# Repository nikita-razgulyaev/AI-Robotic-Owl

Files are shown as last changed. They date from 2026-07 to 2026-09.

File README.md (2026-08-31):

<div align="center">

# 🦉 AI Robotic Owl

**Интерактивный робот-сова с искусственным интеллектом**
3D-печатная механика · 18 сервоприводов на ESP32-S3 · голосовой AI-сервер






</div>

---

## О проекте

**AI Robotic Owl** — роботизированная модель совы с ИИ: голосовой ассистент с характером, который слышит, видит, говорит и двигается. Проект объединяет три независимые, но тесно связанные части — 3D-печатный корпус, прошивку контроллера и AI-сервер.

## 📁 Структура репозитория

```
ai-robotic-owl/
├── AI-Robot-Server/          # Серверная часть: WebSocket-панель, LLM, STT, TTS
├── 3d-model-for-owl/         # 3D-модели корпуса для печати (Fusion 360 + STL)
├── arduino-owl-model/        # Прошивка ESP32-S3: сервоприводы, микрофон, камера, динамик
├── .gitattributes
└── README.md
```

---

## 🧠 Компоненты

### [`AI-Robot-Server/`](./AI-Robot-Server)

Голосовой AI-мозг робота: принимает аудио/видео с ESP32-S3 по WebSocket, распознаёт речь, генерирует ответы персонажа через LLM, синтезирует голос и рассчитывает позы сервоприводов — плюс веб-панель для мониторинга и ручного управления.

**Стек:** Python, FastAPI, WebSocket, Uvicorn · llama-cpp-python, ster-whisper, Silero, edge-tts · YOLOv8, MediaPipe, OpenCV · Qdrant

Полное описание архитектуры, API и запуска — в [`AI-Robot-Server/README.md`](./AI-Robot-Server/README.md).

### [`3d-model-for-owl/`](./3d-model-for-owl)

Набор 3D-моделей корпуса для FDM-печати: голова, тело, крылья, хвост, ноги — каждая деталь в отдельном боксе для удобства печати и сборки.

```
├── fusion/               # Исходники Fusion 360 (.f3d)
│   ├── head.f3d
│   ├── body.f3d
│   ├── wing box.f3d
│   ├── wings.f3d
│   ├── tail box.f3d
│   ├── tail.f3d
│   ├── leg box.f3d
│   └── legs.f3d
└── stl/                  # Готовые к печати STL по тем же узлам
    ├── head/...
    ├── body/...
    ├── wing box/...
    ├── wings/...
    ├── tail box/...
    ├── tail/...
    ├── leg box/...
    └── legs/...
```

**Материалs:** PLA/PETG

### [`arduino-owl-model/`](./arduino-owl-model)

Прошивка контроллера **ESP32-S3**: держит WebSocket-соединение с сервером, стримит аудио с микрофона и видео с камеры, воспроизводит голос через динамик, отрабатывает команды на 18 сервоприводов и управляет LED-подсветкой подставки.

**Особенности:**

- Управление **18 сервоприводами** с плавной интерполяцией движений
- Захват и стрим кадров с камеры (адаптивный FPS в зависимости от того, есть ли лицо в кадре)
- Захват и стрим аудио с микрофона, воспроизведение ответов на динамик
- Автопереподключение к Wi-Fi и WebSocket-серверу с heartbeat

---

## 🔧 Аппаратная платформа

| Компонент | Спецификация |
| --- | --- |
| Микроконтроллер | **ESP32-S3** (Wi-Fi, PSRAM) |
| Драйвер сервоприводов | PCA9685, 16-канальный, I2C (адрес `0x40`) |
| Сервоприводы | 18× SG90 / MG90S — 16 через PCA9685 + 2 напрямую с ESP32-S3 (крен головы, клюв) |
| Микрофон | INMP441, цифровой, шина I2S |
| Динамик | 4 Ом / 3 Вт + усилитель MAX98357A, I2S |
| Камера | OV2640 |
| Подсветка | Адресная LED-лента (подставка) |
| Питание сервоприводов | Внешний BEC 5V, 6A+ (отдельно от логики ESP32) |

> Полная распиновка I2C/I2S/камеры и таблица всех 18 индексов сервоприводов — в [`AI-Robot-Server/README.md`](./AI-Robot-Server/README.md#аппаратная-часть).

---

## 🚀 Быстрый старт

### 1. Аппаратная сборка

1. Распечатайте детали из [`3d-model-for-owl/stl`](./3d-model-for-owl/stl).
2. Установите сервоприводы в корпус согласно узлам сборки.
3. Подключите PCA9685 к ESP32-S3 по I2C и разместите микрофон, камеру и динамик по месту.
4. Обеспечьте отдельное питание 5V для сервоприводов с общей землёй с ESP32.

### 2. Прошивка контроллера

```bash
cd arduino-owl-model
# Откройте проект в Arduino IDE / PlatformIO
# Установите библиотеки: Adafruit PWM Servo Driver, ESP32Servo, ArduinoJson
# Выберите плату: ESP32S3 Dev Module
# Загрузите прошивку
```

### 3. Запуск AI-сервера

```bash
cd AI-Robot-Server
pip install -r requirements.txt
python websocket_server.py
```

Панель управления будет доступна по адресу `http://localhost:8765/panel`. Подробности — в README сервера.

---

## 🎯 Возможности

- 🎙️ Голосовой диалог с персонажем через AI (STT → LLM → TTS)
- 🦉 Живые движения: поворот и наклон головы, взмах крыльев, открытие клюва
- 👁️ Компьютерное зрение — слежение за лицом собеседника
- 🎭 Реакции на контекст разговора через позы сервоприводов
- 📱 Веб-панель для мониторинга, ручного управления и переключения режимов

---

## 📄 Лицензия

Проект распространяется под лицензией **[MIT](./LICENSE)**.

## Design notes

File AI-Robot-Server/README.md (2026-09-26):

<div align="center">

# 🦉 AI Robot Server — Сорен

**Локальный AI-сервер для роботизированной совы на ESP32-S3**
Голосовое управление · Компьютерное зрение · 18 сервоприводов

<p align="center">
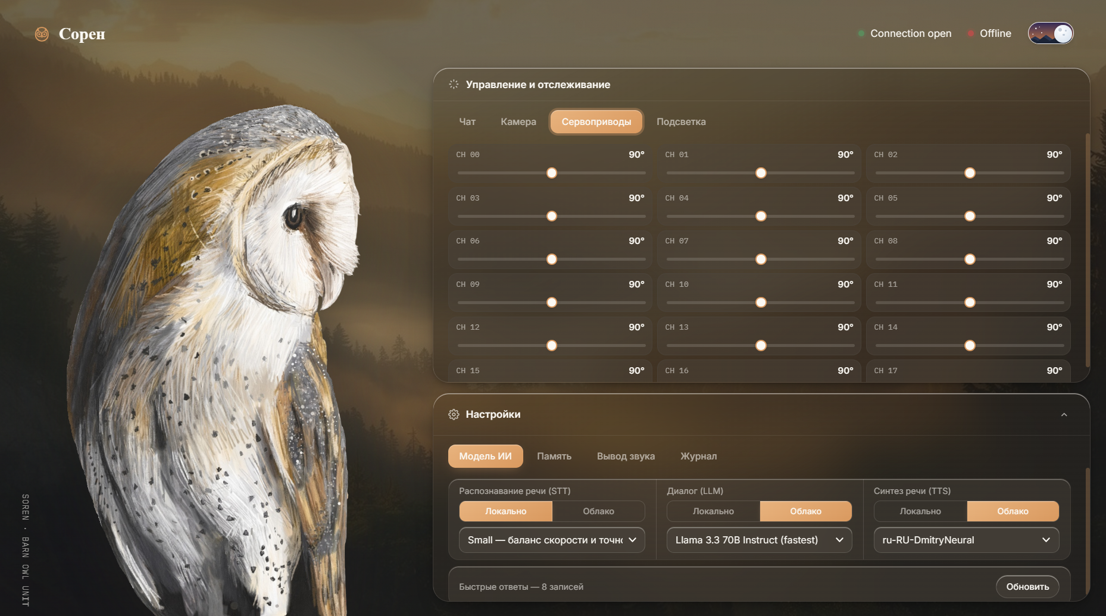
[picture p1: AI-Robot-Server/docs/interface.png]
Панель управления Robot AI Server
  
</p>






</div>

---

## О проекте

**Сорен** — амбарная сова, cтраж Великого Древа Га'Хула из книг Кэтрин Ласки «Легенды ночных стражей», воплощённая в виде физического робота на базе **ESP32-S3**. Этот репозиторий — серверная часть проекта: локальный AI-сервер, который распознаёт речь, генерирует ответы в характере персонажа, синтезирует голос и управляет 18 сервоприводами робота в реальном времени.

Проект объединяет полный voice AI pipeline (STT → LLM → TTS), компьютерное зрение и физическое поведение робота в единую систему с веб-панелью управления.

### Ключевые возможности

- 🎙️ **Голосовой диалог** — распознавание речи, генерация ответа персонажа, синтез голоса
- 🧠 **LLM-персонаж с памятью** — Qwen 7B (дообученный на датасете персонажа) + векторная память (Qdrant) + RAG по биографии и миру Сорена
- 👁️ **Компьютерное зрение** — детекция объектов (YOLOv8), трекинг позы и лиц (MediaPipe/OpenCV)
- 🎭 **Эмоциональный движок** — 7 эмоциональных состояний с уникальными позами сервоприводов и подсветкой глаз
- 🔀 **Local / Cloud переключение** — каждый AI-модуль (STT, LLM, TTS) можно переключать между локальным инференсом и облачным API одной кнопкой
- 🦾 **Управление 18 сервоприводами** — голова, крылья, тело, хвост, лапы, глаза
- 🌐 **Веб-панель управления** — голосовой и текстовый чат, ручное управление сервоприводами, переключение режимов, анимации

---

## Демонстрация переключения Local / Cloud

Каждый AI-модуль имеет независимую кнопку переключения режима — удобно для баланса между приватностью/офлайн-работой и качеством/скоростью.

| Модуль | Локально | Облачно |
| --- | --- | --- |
| **STT** 🎤 | faster-whisper (~500 МБ) | — |
| **LLM** 🧠 | Qwen 2.5 7B GGUF (~4.5 ГБ) | GitHub Models API (gpt-4o-mini) |
| **TTS** 🔊 | Silero (~120 МБ) | edge-tts (Microsoft, бесплатно) |

---

## Технологический стек

`FastAPI` · `faster-whisper` · `llama-cpp-python` · `PyTorch / Silero` · `edge-tts` · `YOLOv8` · `MediaPipe` · `OpenCV` · `webrtcvad` · `Qdrant`

| Компонент | Технология | Назначение |
| --- | --- | --- |
| WebSocket / HTTP сервер | FastAPI + Uvicorn + websockets | API для ESP32 и веб-панели |
| STT (речь → текст) | faster-whisper | Распознавание речи (локально) |
| LLM (языковая модель) | llama-cpp-python / GitHub Models API | Генерация ответов Сорена |
| TTS (текст → речь) | Silero (PyTorch) / edge-tts | Синтез голоса |
| Долгосрочная память | Qdrant (векторная БД) | Память диалогов и контекста |
| Vision | Ultralytics YOLOv8 + MediaPipe + OpenCV | Детекция объектов, позы, лиц |
| Audio VAD | webrtcvad | Определение начала/конца речи |
| Fine-tuning | PEFT (LoRA/QLoRA) + Transformers + Accelerate | Дообучение LLM на персонаже |
| Аудиообработка | soundfile + librosa | Конвертация форматов, ресемплинг |
| Конфигурация | python-dotenv | Переменные окружения |

---

## Архитектура

```
ESP32-S3 (робот) ──WebSocket──▶  FastAPI-сервер  ──▶  STT → LLM → TTS
     ▲   18 сервоприводов              │
     │   микрофон / динамик            ├──▶ Vision (YOLOv8, MediaPipe)
     │   камера                        ├──▶ Эмоциональный движок → позы сервоприводов
     └──────────── аудио/команды ◀─────┴──▶ Веб-панель управления (/panel)
```

---

## Быстрый старт

### 1. Установка зависимостей

```bash
python -m venv venv
venv\Scripts\activate      # Windows
source venv/bin/activate   # Linux / macOS

pip install -r requirements.txt
```

### 2. Настройка конфигурации

```bash
cp .env.example .env
# укажи GITHUB_MODELS_KEY в .env, если нужен облачный LLM
```

### 3. Загрузка моделей

```bash
python download_qwen.py   # LLM — Qwen 7B GGUF
python download_yolo.py   # Vision — YOLOv8
# Whisper и Silero скачаются автоматически при первом запуске
```

### 4. Запуск сервера

```bash
python websocket_server.py
```

Панель управления будет доступна по адресу: **http://localhost:8765/panel**

---

## Веб-панель управления

Панель (`/panel`) объединяет всё управление роботом в одном интерфейсе:

- Переключение режимов **Local / Cloud** для STT, LLM и TTS
- Переключение аудио-ввода (микрофон) и аудио-вывода (динамик)
- Голосовой чат и текстовый чат с Сореном
- Запуск анимаций: `wave`, `nod`, `shake_head`, `idle`
- Ручное управление каждым из 18 сервоприводов
- Отображение текущего статуса сервера и AI-модулей

---

## Персонаж Сорен

### Память и знания (RAG)

База знаний персонажа включает биографию, отношения с ключевыми персонажами, лор мира Га'Хула и философию — используется для контекстно-точных ответов в характере персонажа. Долгосрочная память диалогов хранится в векторной БД Qdrant.

---

## Аппаратная часть

Прошивка ESP32-S3 (`esp32_ai_robot_server.ino`) подключается к серверу по WebSocket (`/ws`, порт 8765), стримит аудио с микрофона и видео с камеры, принимает аудио-ответы и команды на сервоприводы, автоматически переподключается и восстанавливает прерванную фразу после обрыва Wi-Fi.

**Электроника:** ESP32-S3 (PSRAM) · PCA9685 (16-канальный I2C PWM-драйвер) · 18 сервоприводов · INMP441 (I2S-микрофон) · OV2640 (камера) · динамик с усилителем MAX98357A (I2S) · адресная LED-лента (подставка) · W5500 (Ethernet по SPI, резерв — Wi-Fi)

### Сервоприводы (18 каналов, индексы 0–17)

16 каналов идут через **PCA9685** (I2C, адрес `0x40`, 50 Гц, шина на GPIO 4/5), ещё 2 — напрямую с ESP32-S3 через LEDC PWM (50 Гц, 16 бит):

| Индекс | Имя | Назначение | Канал |
| --- | --- | --- | --- |
| 0 | `L_FLAP` | Левое крыло — взмах | PCA9685 |
| 1 | `L_FOLD` | Левое крыло — складывание  | PCA9685 |
| 2 | `R_FLAP` | Правое крыло — взмах | PCA9685 |
| 3 | `R_FOLD` | Правое крыло — складывание | PCA9685 |
| 4 | `WING_TILT` | Наклон крыльев (общий) | PCA9685 |
| 5 | `L_LEG_TURN` | Левая нога — поворот | PCA9685 |
| 6 | `L_LEG_FOLD` | Левая нога — сгиб | PCA9685 |
| 7 | `L_LEG_LIFT` | Левая нога — подъём | PCA9685 |
| 8 | `R_LEG_TURN` | Правая нога — поворот | PCA9685 |
| 9 | `R_LEG_FOLD` | Правая нога — сгиб | PCA9685 |
| 10 | `R_LEG_LIFT` | Правая нога — подъём | PCA9685 |
| 11 | `TAIL_YAW` | Хвост — поворот | PCA9685 |
| 12 | `TAIL_SPREAD` | Хвост — раскрытие | PCA9685 |
| 13 | `TAIL_LIFT` | Хвост — подъём | PCA9685 |
| 14 | `HEAD_YAW` | Голова — влево/вправо | PCA9685 |
| 15 | `HEAD_PITCH` | Голова — вперёд/назад | PCA9685 |
| 16 | `HEAD_ROLL_INDEX` | Голова — крен вбок | GPIO 38 |
| 17 | `BEAK_INDEX` | Открытие клюва | GPIO 39 |

Углы сервоприводов сглаживаются интерполяцией (шаг ≤4°, каждые 10 мс), чтобы движения выглядели плавно, а не рывками.

### Аудио (I2S)

| Узел | Роль | Пины (BCLK / WS·LRC / DATA) | Частота дискретизации |
| --- | --- | --- | --- |
| INMP441 | Микрофон (RX) | GPIO 1 / 3 / 2 | 16 кГц |
| MAX98357A | Усилитель/динамик (TX) | GPIO 40 / 41 / 42 | 48 кГц |

Динамик работает через кольцевой буфер в PSRAM с джиттер-буфером (~125 мс) и fade-in каждой новой фразы; во время воспроизведения и 400 мс после микрофон программно глушится, чтобы не ловить эхо.

### Камера (OV2640)

Данные: D0–D7 → GPIO 11, 9, 8, 10, 12, 18, 17, 16 · PCLK → GPIO 13 · VSYNC → GPIO 6 · HREF → GPIO 7 · SIOD/SIOC (I2C) → GPIO 14/21 · RESET → GPIO 15. Разрешение QVGA (320×240), адаптивный FPS: 3 кадра/с в режиме ожидания, 15 кадров/с при обнаруженном лице/активном диалоге.

### Подсветка подставки

Адресная LED-лента (NeoPixel, 60 светодиодов) на GPIO 47 — тёплая белая подсветка с плавной анимацией включения/выключения, управляется командой `backlight` с сервера.

### Сеть и связь

ESP32-S3 в первую очередь пытается поднять **Ethernet** (модуль W5500 по SPI); если за 4 секунды линк/IP не появились — автоматически откатывается на **Wi-Fi**. Выбор делается один раз при старте. В обоих случаях держится постоянное WebSocket-соединение с сервером (heartbeat каждые 30 с, таймаут 60 с, автопереподключение раз в 5 с). При обрыве связи во время озвучки фраза запрашивается заново после восстановления соединения.

**Ethernet (W5500, SPI):**

| Сигнал | GPIO | Примечание |
| --- | ---- | --- |
| SCK | 0 | strapping-пин (кнопка BOOT); не жать BOOT во время работы |
| MISO | 46 | input-only на ESP32-S3 |
| MOSI | 19 | физически совпадает с нативным USB (USB_D-) |
| CS | 20 | физически совпадает с нативным USB (USB_D+) |
| RST | 48 | |

Пины 19/20/43/44 (нативный USB и штатный UART0/CP2102) — единственный «дефолтный» вариант под SPI на этой плате (ESP32-S3-DevKitC-1, модуль WROOM-1 `-N16R8`, Octal PSRAM): GPIO22-25 не выведены на разъём, GPIO35-37 заняты Octal PSRAM. Текущая раскладка (SCK=0, MISO=46) освобождает GPIO43/44 обратно под UART0, чтобы Serial-логи оставались доступны через штатный CP2102-порт, пока Ethernet активен.

IP настраивается статически через `ETH.config(...)` **после** `ETH.begin()` (для DHCP-присвоения нужен DHCP-сервер в сети, которого нет при прямом соединении ПК↔робот через USB-Ethernet переходник). Адрес сервера, к которому подключается плата, задаётся константой `SERVER_HOST` в прошивке и должен совпадать со статическим IP компьютера на соответствующем сетевом адаптере.

---

## API

| Endpoint | Метод | Описание |
| --- | ----- | --- |
| `/` | GET | Статус сервера |
| `/status` | GET | Полный статус и режимы AI-модулей |
| `/audio_mode` | POST  | Переключение аудио (вход/выход) |
| `/ai_mode` | POST  | Переключение AI-модуля (stt/tts/llm) |
| `/speak` | POST  | Текст → LLM → TTS → аудио |
| `/voice` | POST  | Аудио → STT → LLM → TTS → аудио |
| `/panel` | GET | Веб-панель управления (HTML) |
| `/ws` | WS | WebSocket-канал для ESP32 |

---

## Тестирование

```bash
python check_model.py    # Проверка целостности LLM-модели
python test_server.py    # Тест сервера без физического ESP32
python test_github.py    # Тест GitHub Models API
python test_all.py       # Полное тестирование всех модулей
```

---

## Требования

- **Python:** 3.10 – 3.11
- **ОЗУ:** от 8 ГБ (для локального Qwen 7B)
- **Диск:** ~5 ГБ под модели
- **ОС:** Windows 10/11, Linux, macOS

---

## Структура проекта

```
robot_server/
├── websocket_server.py      # Главный WebSocket-сервер + веб-панель
├── config.yaml               # Основной конфиг (модели, сеть, режимы)
├── requirements.txt
├── .env / .env.example
├── config/                  # Настройки сервера, AI, сервоприводов, анимаций
├── modules/                 # AI-модули: stt, tts, llm, vision, robot_brain,
│                             #   servo_controller, audio_buffer, fuzzy_matcher, memory
├── character/                # System prompt, RAG-чанки, карта эмоций Сорена
├── audio_cache/              # Заранее сгенерированные аудио-ответы (quick answers)
├── memory/                   # Долгосрочная память диалогов
├── qdrant_storage/            # Локальное хранилище векторной БД Qdrant
├── models/                   # AI-модели (скачиваются автоматически)
├── llama-bin/                 # Бинарники llama.cpp для локального LLM-инференса
├── datasets/                  # Датасеты для fine-tuning персонажа
├── scripts/                  # Загрузка/подготовка моделей, датасета, fine-tuning
├── static/panel/              # Ассеты веб-панели
├── docs/                      # Документация, скриншоты
├── .github/                   # CI/шаблоны GitHub
└── .vscode/                   # Настройки редактора
```

---

## Лицензия

Проект распространяется под лицензией **[MIT](./LICENSE)**.

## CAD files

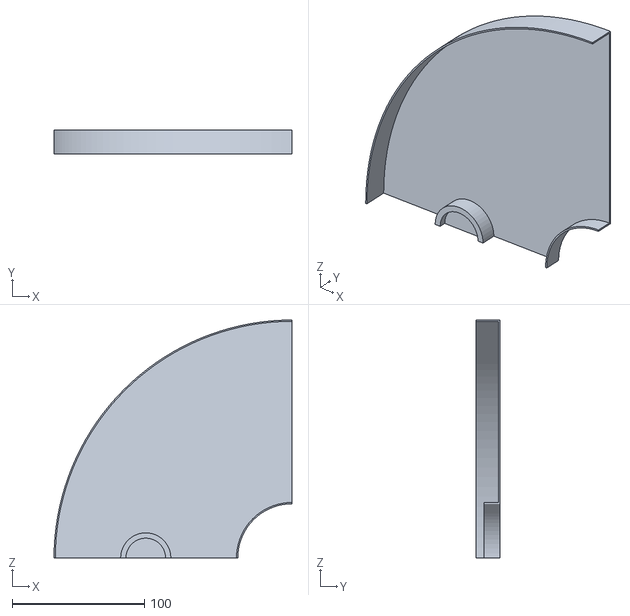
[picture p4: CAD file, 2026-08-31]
3d-model-for-owl/stl/base/base (2).stl
180.0 x 18.0 x 180.0

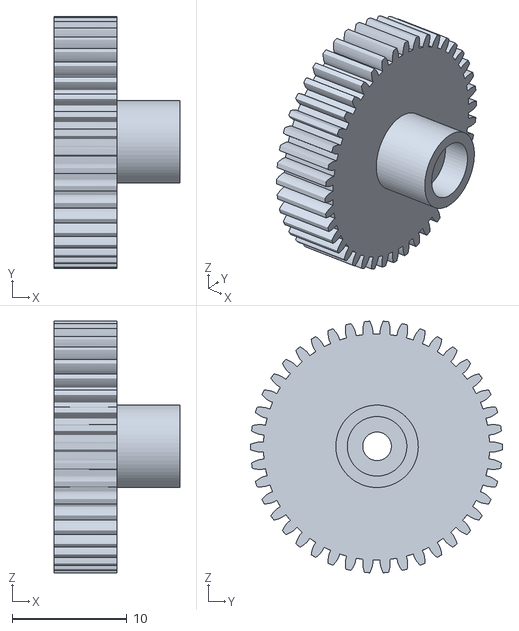
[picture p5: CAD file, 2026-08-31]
3d-model-for-owl/stl/body/tilt gear.stl
11.0 x 22.0 x 22.0

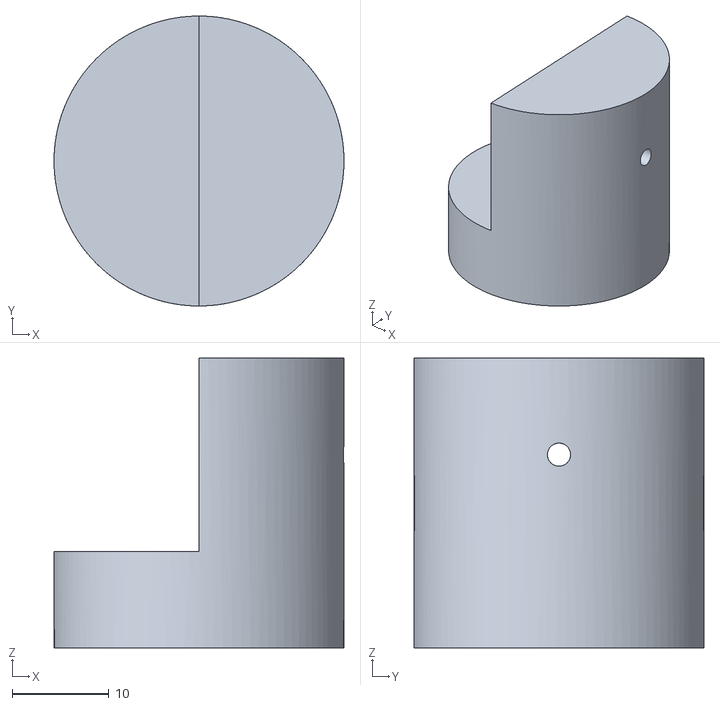
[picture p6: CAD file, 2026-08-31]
3d-model-for-owl/stl/clamp/clamp.stl
30.0 x 30.0 x 30.0

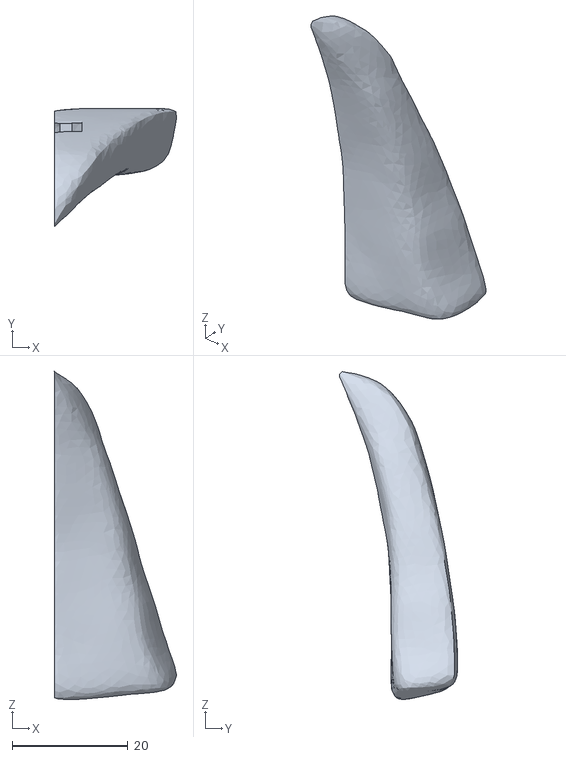
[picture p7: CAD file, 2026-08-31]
3d-model-for-owl/stl/head/left lower jaw.stl
21.1 x 20.5 x 56.7

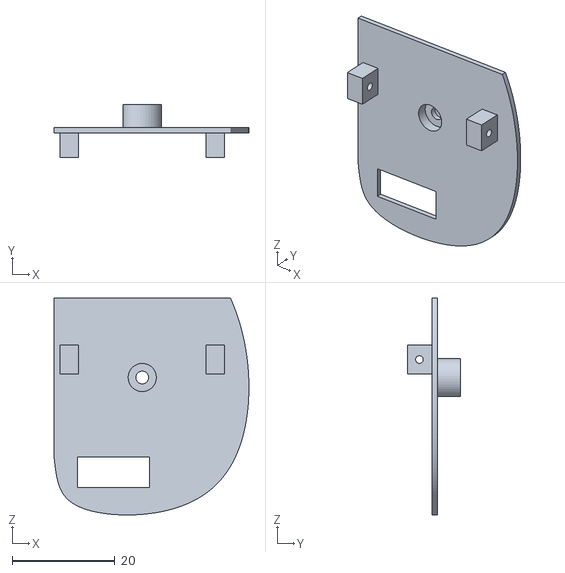
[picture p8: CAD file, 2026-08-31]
3d-model-for-owl/stl/leg box/left leg box head.stl
38.0 x 10.3 x 42.3

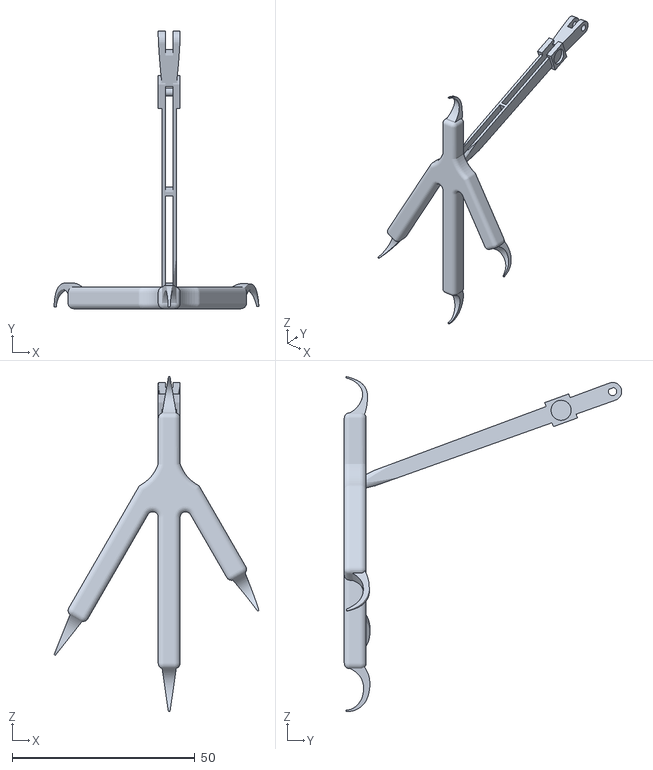
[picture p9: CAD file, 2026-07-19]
3d-model-for-owl/stl/legs/part 3.stl
56.0 x 75.9 x 91.6

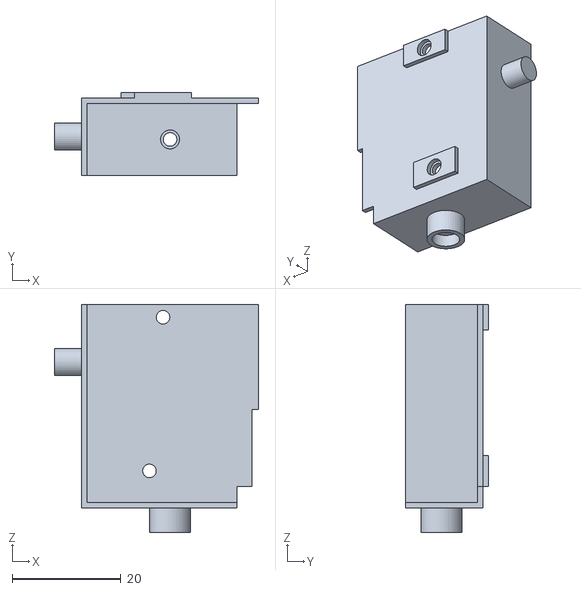
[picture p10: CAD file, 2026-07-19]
3d-model-for-owl/stl/tail box/tail box head.stl
37.6 x 15.3 x 42.0

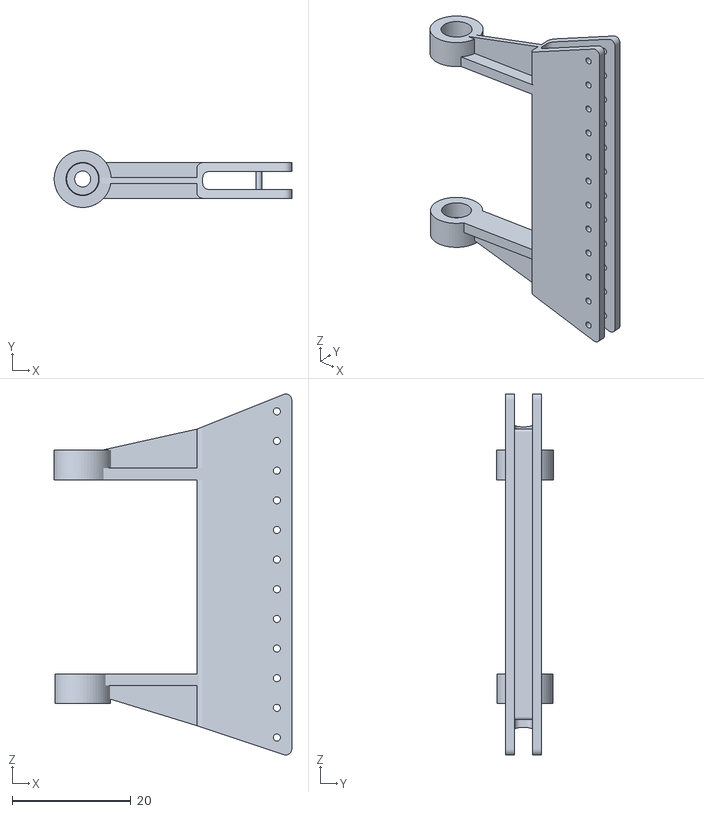
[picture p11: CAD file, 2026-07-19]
3d-model-for-owl/stl/tail/tail.stl
40.1 x 9.59 x 60.9

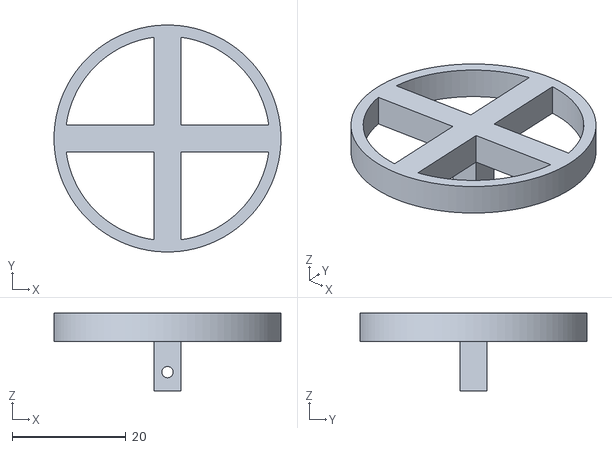
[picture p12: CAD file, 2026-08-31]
3d-model-for-owl/stl/wing box/roll 1.stl
40.0 x 40.0 x 13.7

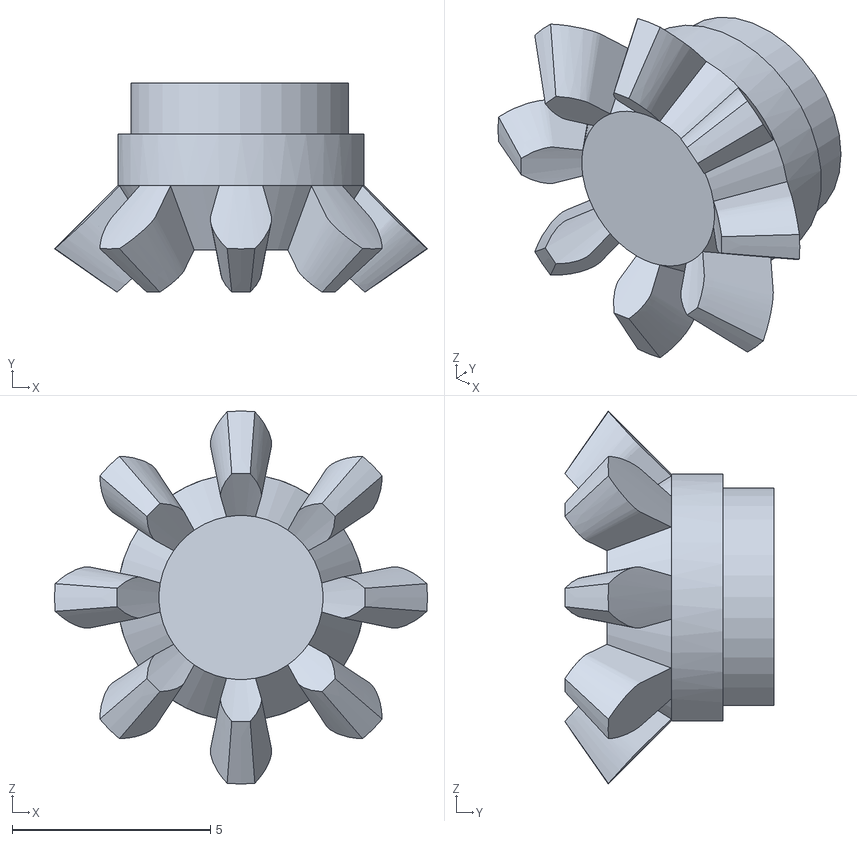
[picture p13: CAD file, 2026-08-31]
3d-model-for-owl/stl/wings/left pt 1 bl gr.stl
9.41 x 5.28 x 9.41

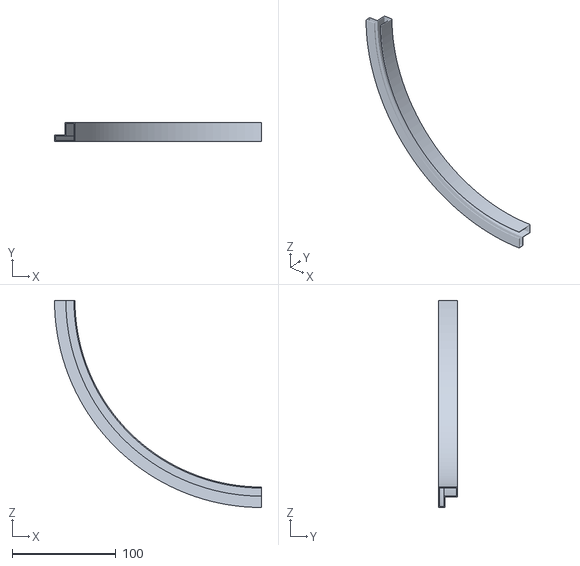
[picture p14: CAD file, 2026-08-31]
3d-model-for-owl/stl/base/light ring (1).stl
200.0 x 18.0 x 200.0

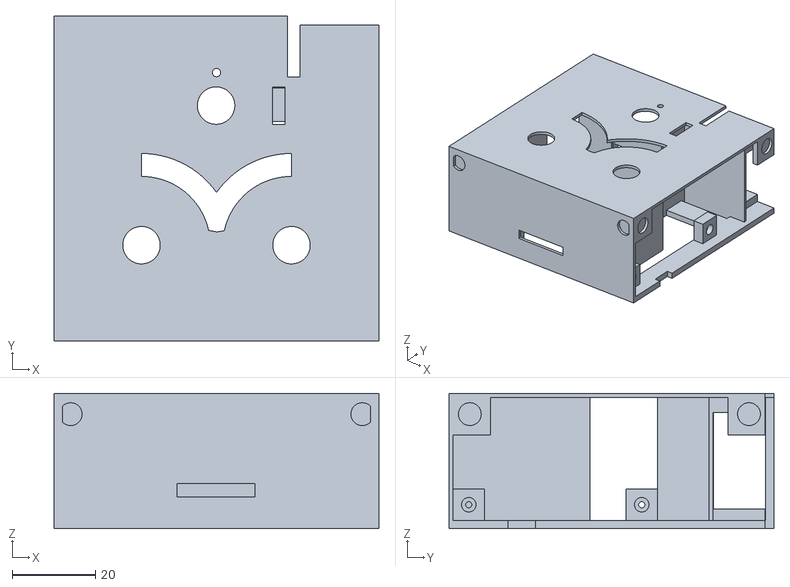
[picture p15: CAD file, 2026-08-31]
3d-model-for-owl/stl/body/body(2).stl
78.0 x 78.0 x 32.5

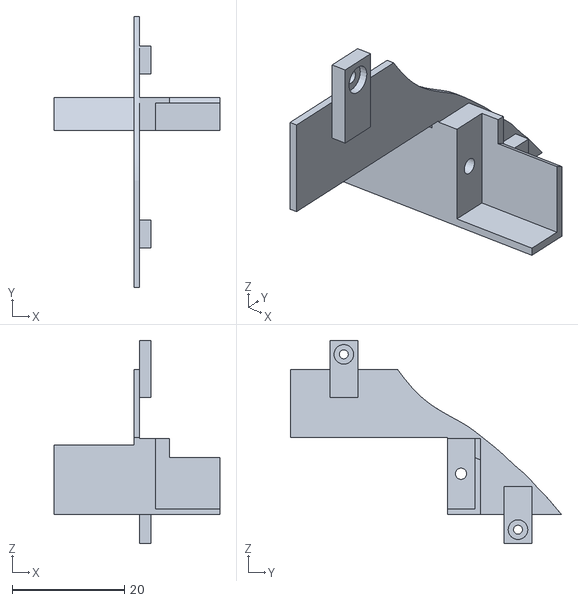
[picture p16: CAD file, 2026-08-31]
3d-model-for-owl/stl/head/forehead.stl
29.5 x 48.2 x 36.2

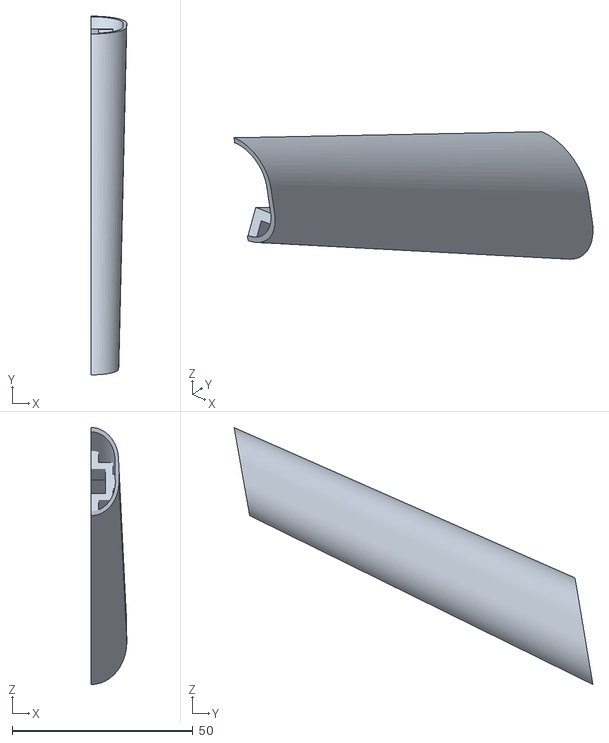
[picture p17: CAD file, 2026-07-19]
3d-model-for-owl/stl/legs/part 2 case (2).stl
9.86 x 99.3 x 71.1

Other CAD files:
3d-model-for-owl/stl/leg box/right leg box head.stl
3d-model-for-owl/stl/tail box/tail box.stl
3d-model-for-owl/stl/tail/holder 1.stl
3d-model-for-owl/stl/wing box/fold gear.stl
3d-model-for-owl/fusion/base.f3d
3d-model-for-owl/fusion/body.f3d
3d-model-for-owl/fusion/clamp.f3d
3d-model-for-owl/fusion/eyes.f3d
3d-model-for-owl/fusion/leg box.f3d
3d-model-for-owl/fusion/tail box.f3d
3d-model-for-owl/fusion/tail.f3d
3d-model-for-owl/fusion/wing box.f3d
3d-model-for-owl/fusion/wings.f3d
3d-model-for-owl/stl/base/base (1).stl
3d-model-for-owl/stl/base/base (3).stl
3d-model-for-owl/stl/base/base (4).stl
3d-model-for-owl/stl/base/light ring (2).stl
3d-model-for-owl/stl/base/light ring (3).stl
3d-model-for-owl/stl/base/light ring (4).stl
3d-model-for-owl/stl/base/outer ring (1).stl
3d-model-for-owl/stl/base/outer ring (2).stl
3d-model-for-owl/stl/base/outer ring (3).stl
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

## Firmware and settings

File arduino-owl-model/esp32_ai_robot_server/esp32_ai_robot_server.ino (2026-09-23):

/* 🦉 Robot ESP32-S3 Firmware - Soren */

#include <WiFi.h>
#include <ETH.h>
#include <SPI.h>
#include <WebSocketsClient.h>
#include <Wire.h>
#include <Adafruit_PWMServoDriver.h>
#include <driver/i2s.h>
#include <esp_camera.h>
#include <ArduinoJson.h>
#include <Adafruit_NeoPixel.h>
#include <esp_task_wdt.h>

// ==================== КОНФИГУРАЦИЯ ====================
const char* WIFI_SSID = "TP-Link_208E";
const char* WIFI_PASSWORD = "31267649";
const char* SERVER_HOST = "192.168.50.10";  // статический IP ПК на адаптере TP-LINK USB-Ethernet
const char* DEVICE_KEY = "";
const int SERVER_PORT = 8765;

// ---------- ETHERNET (модуль W5500 по SPI) ----------
// GPIO0/45/46 — strapping-пины ESP32-S3: их уровень чип читает В МОМЕНТ
// СБРОСА, чтобы выбрать режим загрузки. Внешнее устройство на них (было тут
// раньше — 0=MOSI, 46=CS) срывает это определение при каждом
// авто-сбросе/заливке ("Wrong boot mode detected"). Поэтому SPI переехал на
// GPIO19/20/43/44 — ни один из них не strapping и не PSRAM (33-37).
//
// ВАЖНО: GPIO43/44 по умолчанию — консольный UART на CP2102 ("UART"-порт).
// Заняв их под Ethernet, Serial-вывод для отладки нужно смотреть через
// ВТОРОЙ, нативный USB-порт платы ("USB"), и в Arduino IDE включить
// Tools → USB CDC On Boot → Enabled — иначе Serial.print() будет уходить в
// никуда.
// ПЛАТА: ESP32-S3-DevKitC-1, модуль WROOM-1 -N16R8 (Octal PSRAM).
// ЭКСПЕРИМЕНТ: пробуем вернуть SCK/MISO на strapping-пины 0/46, но НЕ в
// тех же ролях, что раньше сорвали загрузку (было 0=MOSI, 46=CS).
// Теория: SCK всегда ведёт ESP32 (мастер), W5500 (ведомый) его не тянет;
// MISO — вход для ESP32, GPIO46 к тому же input-only. Раньше проблема
// была именно с MOSI/CS на strapping-пинах — не факт, что SCK/MISO
// поведут себя так же. ПРОВЕРИТЬ: после заливки следить за выводом
// esptool — если снова "Wrong boot mode detected"/сбои автосброса на
// каждой заливке, откатывать на 43/44 (см. предыдущую версию комментария
// в истории правок).
#define ETH_PHY_TYPE   ETH_PHY_W5500
#define ETH_PHY_ADDR   1
#define ETH_PHY_CS     20
#define ETH_PHY_IRQ    -1
#define ETH_PHY_RST    48
#define ETH_SPI_SCK    0
#define ETH_SPI_MISO   46
#define ETH_SPI_MOSI   19

#define ETH_CONNECT_TIMEOUT_MS 4000  // сколько ждём линк+DHCP на Ethernet при старте,
                                      // прежде чем откатиться на Wi-Fi
#define WIFI_FALLBACK_TIMEOUT_MS 20000

bool ethConnected = false;      // Ethernet реально поднят и получил IP прямо сейчас
bool wifiFallbackActive = false; // на этом старте работаем через Wi-Fi (Ethernet не найден/не подключен)

// ---------- СЕРВОПРИВОДЫ ----------
Adafruit_PWMServoDriver pca = Adafruit_PWMServoDriver(0x40);
const int PCA_FREQ = 50;
const int SERVO_17_PIN = 38;
const int SERVO_18_PIN = 39;

// ESP32-S3 аппаратно поддерживает МАКСИМУМ 14 бит разрешения на канал LEDC
// (в отличие от классического ESP32, где было 20 бит). Раньше здесь стояло 16 —
// ledcAttach() с недопустимым разрешением тихо возвращает false и канал вообще
// не настраивается, поэтому ledcWrite() на GPIO 38/39 ничего не делал — именно
// поэтому сервы HEAD_ROLL/BEAK "не работали".
#define SERVO_GPIO_LEDC_RES_BITS 14
#define SERVO_GPIO_LEDC_MAX_DUTY ((1 << SERVO_GPIO_LEDC_RES_BITS) - 1)  // 16383

// -------------------- ИМЕНОВАННЫЕ ИНДЕКСЫ СЕРВО --------------------
#define L_FLAP          0   // Левое крыло — взмах
#define L_FOLD          1   // Левое крыло — складывание
#define R_FLAP          2   // Правое крыло — взмах
#define R_FOLD          3   // Правое крыло — складывание
#define WING_TILT       4   // Наклон крыльев (общий)
#define L_LEG_TURN      5   // Левая нога — поворот
#define L_LEG_FOLD      6   // Левая нога — сгиб
#define L_LEG_LIFT      7   // Левая нога — подъём
#define R_LEG_TURN      8   // Правая нога — поворот
#define R_LEG_FOLD      9   // Правая нога — сгиб
#define R_LEG_LIFT      10  // Правая нога — подъём
#define TAIL_YAW        11  // Хвост — поворот
#define TAIL_SPREAD     12  // Хвост — раскрытие
#define TAIL_LIFT       13  // Хвост — подъём
#define HEAD_YAW        14  // Голова — влево/вправо (канал PCA9685)
#define HEAD_PITCH      15  // Голова — вперёд/назад (канал PCA9685)
#define HEAD_ROLL_INDEX 16  // Голова — крен вбок. Физически SERVO_17_PIN = GPIO 38
#define BEAK_INDEX      17  // Открытие клюва.       Физически SERVO_18_PIN = GPIO 39

#define PCA_SERVO_COUNT 16  // сколько первых индексов (0-15) идут через PCA9685

#define SERVO_MAX_STEP 3        // потолок скорости (град/тик = 10мс) — верхний предел даже для больших скачков цели
#define SERVO_EASE_FACTOR 0.12  // доля оставшегося расстояния до цели, проходимая за один тик (плавное подтормаживание к концу)
#define SERVO_UPDATE_MS 10
#define SERVO_DEAD_ZONE 1

// ---------- ПОДСВЕТКА ----------
#define STAND_LED_PIN   47
#define STAND_LED_COUNT 60
Adafruit_NeoPixel standLed(STAND_LED_COUNT, STAND_LED_PIN, NEO_GRB + NEO_KHZ800);

#define WARM_WHITE_R 255
#define WARM_WHITE_G 200
#define WARM_WHITE_B 140
bool standBacklightOn = false;

// ---------- I2S ПИНЫ ----------
#define I2S_MIC_BCLK    1
#define I2S_MIC_WS      3
#define I2S_MIC_DIN     2

#define I2S_AMP_BCLK    40
#define I2S_AMP_LRC     41
#define I2S_AMP_DOUT    42

#define SAMPLE_RATE 16000
#define SPEAKER_SAMPLE_RATE 48000

// ---------- КАМЕРА ----------
#define PWDN_GPIO_NUM    -1
#define RESET_GPIO_NUM   15
#define XCLK_GPIO_NUM    -1
#define SIOD_GPIO_NUM    14
#define SIOC_GPIO_NUM    21

// Возвращено на QVGA (320x240) — на HQVGA (240x176) детектор лица на
// зашумлённой ИК-картинке стабильно не проходил порог уверенности
// (FACE_DETECTOR_CONFIDENCE). Прирост FPS слежения берём не за счёт
// разрешения, а за счёт освобождённого CV-потока (убрано слежение за
// губами) и CAM_FPS_FACE ниже.
#define DETECT_FRAME_SIZE  FRAMESIZE_QVGA

#define CAM_FPS_IDLE  3
#define CAM_FPS_FACE  15
unsigned long videoFrameIntervalMs = 1000 / CAM_FPS_IDLE;
unsigned long lastVideoFrameMs = 0;
bool lastFaceDetected = false;

// ==================== ГЛОБАЛЬНЫЕ ====================
WebSocketsClient webSocket;
bool isConnected = false;

int currentServoAngles[18];
int targetServoAngles[18];
unsigned long lastServoUpdateMs = 0;

String currentEyeLed = "soft_white_low";
String audioMode = "robot";

// ---------- МИКРОФОН ----------
#define AUDIO_BUFFER_SIZE 1024
int16_t audioBuffer[AUDIO_BUFFER_SIZE];

#define AUDIO_CHUNK_SAMPLES 480
#define AUDIO_CHUNK_BYTES (AUDIO_CHUNK_SAMPLES * 2)

uint8_t micAccum[AUDIO_CHUNK_BYTES * 8];
size_t micAccumLen = 0;

#define MIC_NOISE_GATE 150
#define MIC_SILENCE_TIMEOUT 1000
unsigned long silenceStartMs = 0;
bool micStreamConfirmed = false;

// ---------- ДИНАМИК (ring buffer) ----------
#define SPK_BUFFER_SIZE 131072
uint8_t* spkRingBuffer = nullptr;
volatile size_t spkWriteIdx = 0;
volatile size_t spkReadIdx = 0;
volatile size_t spkDataLen = 0;

#define SPK_PREBUFFER_BYTES     12000  // ~125 мс на 48кГц/16-бит — запас на джиттер сети
#define SPK_PREBUFFER_STALL_MS  350    // столько ждём тишину, прежде чем считать накопление законченным
#define SPK_END_SILENCE_MS      900    // тишина дольше этого = фраза реально закончилась
bool spkPrebuffering = true;
bool spkEnded = true;               // true = сейчас полная тишина, новых данных не ждём
volatile unsigned long lastSpkPushMs = 0;

// ---------- ВОССТАНОВЛЕНИЕ ПОСЛЕ ОБРЫВА WI-FI ----------
bool utteranceInterrupted = false;

// ---------- КАМЕРА ----------
static uint8_t videPacket[16384];

// ---------- HEARTBEAT ----------
#define HEARTBEAT_INTERVAL_MS 30000
#define HEARTBEAT_TIMEOUT_MS  60000
unsigned long lastHeartbeatSentMs = 0;
unsigned long lastHeartbeatRecvMs = 0;

// ---------- ЭХО-ПОДАВЛЕНИЕ ----------
// Время (мс), на которое микрофон "глухнет" после окончания аудио в буфере,
// чтобы не схватить реверберацию из динамика
#define MIC_DEAF_MS_AFTER_AUDIO 400
static unsigned long lastSpkActiveMs = 0;

// ==================== СЕТЬ (Ethernet первым, Wi-Fi — резерв) ====================
void onNetworkEvent(arduino_event_id_t event, arduino_event_info_t info) {
  switch (event) {
    case ARDUINO_EVENT_ETH_START:
      Serial.println("[ETH] Интерфейс стартовал");
      ETH.setHostname("soren-owl");
      break;
    case ARDUINO_EVENT_ETH_CONNECTED:
      Serial.println("[ETH] Кабель на линке");
      break;
    case ARDUINO_EVENT_ETH_GOT_IP:
      Serial.print("[ETH] ✅ IP получен: ");
      Serial.println(ETH.localIP());
      ethConnected = true;
      break;
    case ARDUINO_EVENT_ETH_LOST_IP:
    case ARDUINO_EVENT_ETH_DISCONNECTED:
    case ARDUINO_EVENT_ETH_STOP:
      if (ethConnected) Serial.println("[ETH] Соединение потеряно");
      ethConnected = false;
      break;
    default:
      break;
  }
}

// Пробует поднять Ethernet (модуль W5500); если за ETH_CONNECT_TIMEOUT_MS
// линк/IP не появился (кабель не воткнут или модуль не распаян) — откатывается
// на Wi-Fi, как раньше. Выбор делается один раз при старте.
void connectNetwork() {
  Network.onEvent(onNetworkEvent);

  Serial.println("[NET] Пробую Ethernet (W5500)...");
  SPI.begin(ETH_SPI_SCK, ETH_SPI_MISO, ETH_SPI_MOSI, ETH_PHY_CS);
  ETH.begin(ETH_PHY_TYPE, ETH_PHY_ADDR, ETH_PHY_CS, ETH_PHY_IRQ, ETH_PHY_RST, SPI);

  // ETH.config() обязательно ПОСЛЕ ETH.begin() — до begin() сетевой
  // интерфейс ещё не создан, вызов молча игнорируется (или роняет в
  // панику на некоторых версиях core), и плата тихо продолжает ждать
  // DHCP, как будто config() не было. Статика: прямое соединение
  // ПК↔робот через USB-Ethernet переходник без DHCP-сервера.
  IPAddress staticIP(192, 168, 50, 20);
  IPAddress gateway(192, 168, 50, 10);
  IPAddress subnet(255, 255, 255, 0);
  ETH.config(staticIP, gateway, subnet);

  unsigned long ethWaitStart = millis();
  while (!ethConnected && millis() - ethWaitStart < ETH_CONNECT_TIMEOUT_MS) {
    delay(100);
  }

  if (ethConnected) {
    Serial.println("[NET] ✅ Работаем через Ethernet");
    return;
  }

  Serial.println("[NET] Ethernet не поднялся (нет кабеля/модуля) — переключаюсь на Wi-Fi");
  wifiFallbackActive = true;
  WiFi.begin(WIFI_SSID, WIFI_PASSWORD);
  Serial.print("[NET] Connecting to WiFi");
  unsigned long wifiWaitStart = millis();
  while (WiFi.status() != WL_CONNECTED && millis() - wifiWaitStart < WIFI_FALLBACK_TIMEOUT_MS) {
    delay(500);
    Serial.print(".");
  }
  Serial.println();
  if (WiFi.status() == WL_CONNECTED) {
    Serial.print("[NET] ✅ Работаем через Wi-Fi, IP: ");
    Serial.println(WiFi.localIP());
  } else {
    Serial.println("[NET] ⚠️ Wi-Fi тоже не подключился за таймаут — "
                    "продолжаю пробовать в фоне (WiFi сам переподключается)");
  }
}

// ==================== SETUP ====================
void setup() {
  Serial.begin(115200);
  delay(1000);
  Serial.println("\n🦉 Soren ESP32-S3 v4.2 Starting...");

  Serial.printf("PSRAM: %d KB total, %d KB free\n",
    ESP.getPsramSize() / 1024, ESP.getFreePsram() / 1024);

  standLed.begin();
  standLedBootAnimation();

  Wire.begin(4, 5);

  Serial.println("[I2C] Скан шины...");
  int i2cFound = 0;
  for (uint8_t addr = 1; addr < 127; addr++) {
    Wire.beginTransmission(addr);
    if (Wire.endTransmission() == 0) {
      Serial.printf("[I2C]   найдено устройство на 0x%02X%s\n", addr,
                    addr == 0x40 ? "  ← ожидаемый адрес PCA9685" : "");
      i2cFound++;
    }
  }
  if (i2cFound == 0) {
    Serial.println("[I2C] ⚠️ НИЧЕГО не найдено на шине! Проверь SDA/SCL (пины 4/5), "
                    "питание VCC самого PCA9685 (не путать с V+ для серв) и общую землю.");
  }

  pca.begin();

  Wire.end();
  Wire.begin(4, 5);

  pca.setPWMFreq(PCA_FREQ);

  bool attach17 = ledcAttach(SERVO_17_PIN, 50, SERVO_GPIO_LEDC_RES_BITS);
  bool attach18 = ledcAttach(SERVO_18_PIN, 50, SERVO_GPIO_LEDC_RES_BITS);
  if (!attach17) Serial.println("❌ ledcAttach GPIO38 (HEAD_ROLL) FAILED");
  if (!attach18) Serial.println("❌ ledcAttach GPIO39 (BEAK) FAILED");

  for (int i = 0; i < 18; i++) {
    currentServoAngles[i] = 90;
    targetServoAngles[i] = 90;
  }
  for (int i = 0; i < PCA_SERVO_COUNT; i++) setServoAngle(i, 90);
  setServoAngle(HEAD_ROLL_INDEX, 90);
  setServoAngle(BEAK_INDEX, 90);

  initI2SMic();
  initI2SSpeaker();

  if (ESP.getPsramSize() > 0) {
    spkRingBuffer = (uint8_t*)ps_malloc(SPK_BUFFER_SIZE);
    if (spkRingBuffer) {
      Serial.printf("✅ Speaker ring buffer: %d bytes in PSRAM\n", SPK_BUFFER_SIZE);
    } else {
      Serial.println("⚠️ PSRAM alloc failed for speaker buffer");
    }
  }

  connectNetwork();

  webSocket.begin(SERVER_HOST, SERVER_PORT, "/ws");
  webSocket.onEvent(webSocketEvent);
  webSocket.setReconnectInterval(5000);

  initCamera();

  lastHeartbeatRecvMs = millis();

  Serial.println("✅ Setup complete!");
  Serial.println("🔊 Audio mode: ROBOT (ESP32 speaker)");
}

bool isAudioPlaying() {
  return !spkEnded;
}

// ==================== LOOP ====================
void loop() {
  webSocket.loop();

  // Если стартовали в резервном Wi-Fi-режиме, а Ethernet потом всё же
  // появился (воткнули кабель) — просто перезагружаемся: чище, чем на лету
  // тушить Wi-Fi и пересобирать сокеты, а плата и так переживает рестарт
  // без потери состояния серв/подсветки (см. device_state на сервере).
  static unsigned long lastEthRecheckMs = 0;
  if (wifiFallbackActive && ethConnected && millis() - lastEthRecheckMs > 3000) {
    lastEthRecheckMs = millis();
    Serial.println("[NET] Ethernet появился во время работы на Wi-Fi — перезагружаюсь, чтобы переехать на него");
    delay(200);
    ESP.restart();
  }

  if (isConnected) {
    // --- Микрофон: глушим во время TTS + 400 мс после, чтобы не поймать эхо ---
    bool micDeaf = isAudioPlaying() || (millis() - lastSpkActiveMs < MIC_DEAF_MS_AFTER_AUDIO);
    if (micDeaf) {
      // Сбрасываем накопленное и сливаем I2S-буфер, чтобы DMA не переполнился
      micAccumLen = 0;
      micStreamConfirmed = false;
      size_t bytesRead = 0;
      i2s_read(I2S_NUM_0, audioBuffer, sizeof(audioBuffer), &bytesRead, 0);
      if (isAudioPlaying()) {
        lastSpkActiveMs = millis();  // продлеваем глухой период
      }
    } else {
      sendAudioChunk();
    }

    feedSpeakerFromRingBuffer();

    unsigned long now = millis();
    if (isAudioPlaying()) {
      lastVideoFrameMs = now;  // не копим "долг" кадров на время озвучки
    } else if (now - lastVideoFrameMs >= videoFrameIntervalMs) {
      lastVideoFrameMs = now;
      sendVideoFrame();
    }

    interpolateServos();

    if (now - lastHeartbeatSentMs >= HEARTBEAT_INTERVAL_MS) {
      sendPing();
      lastHeartbeatSentMs = now;
    }
    if (now - lastHeartbeatRecvMs >= HEARTBEAT_TIMEOUT_MS) {
      Serial.println("[WS] ❌ Heartbeat timeout — forcing reconnect");
      isConnected = false;
      webSocket.disconnect();
    }
  }

  delay(2);
}

// ==================== WEBSOCKET ====================
void webSocketEvent(WStype_t type, uint8_t * payload, size_t length) {
  switch(type) {
    case WStype_DISCONNECTED:
      Serial.println("[WS] Disconnected");
      isConnected = false;
      if (isAudioPlaying()) {
        utteranceInterrupted = true;
      }

      spkWriteIdx = 0;
      spkReadIdx = 0;
      spkDataLen = 0;
      spkPrebuffering = true;
      spkEnded = true;
      if (spkRingBuffer) {
        i2s_zero_dma_buffer(I2S_NUM_1);
      }
      micAccumLen = 0;
      micStreamConfirmed = false;
      break;

    case WStype_CONNECTED:
      Serial.println("[WS] Connected to server");
      isConnected = true;
      lastHeartbeatRecvMs = millis();
      sendPing();
      webSocket.sendTXT("{\"type\":\"audio_mode\"}");

      if (utteranceInterrupted) {
        webSocket.sendTXT("{\"type\":\"audio_resume_request\"}");
        Serial.println("[WS] Запрошен повтор прерванной фразы (audio_resume_request)");
        utteranceInterrupted = false;
      }
      break;

    case WStype_TEXT: {
      String text = String((char*)payload);
      handleServerCommand(text);
      break;
    }

    case WStype_BIN: {
      if (length >= 4) {
        if (memcmp(payload, "AUDI", 4) == 0) {
          size_t audioLen = length - 4;
          Serial.printf("[WS BIN] AUDI received: %u bytes\n", (unsigned)audioLen);
          if (audioMode == "robot") {
            if (spkRingBuffer) {
              pushToSpeakerRing(payload + 4, audioLen);
            } else {
              playAudioDirect(payload + 4, audioLen);
            }
          } else {
            Serial.printf("[Audio] REJECTED — mode=%s\n", audioMode.c_str());
          }
        } else {
          char tag[5] = {0};
          memcpy(tag, payload, 4);
          static unsigned long lastOtherBin = 0;
          if (millis() - lastOtherBin > 3000) {
            Serial.printf("[WS BIN] tag=%s len=%u\n", tag, (unsigned)length);
            lastOtherBin = millis();
          }
        }
      }
      break;
    }

    default:
      break;
  }
}

void handleServerCommand(String& json) {
  StaticJsonDocument<4096> doc;
  DeserializationError error = deserializeJson(doc, json);

  if (error) {
    Serial.print("[WS] JSON parse error: ");
    Serial.println(error.c_str());
    return;
  }

  const char* cmdType = doc["type"];
  if (!cmdType) {
    Serial.println("[WS] WARN: received JSON without 'type' field");
    return;
  }

  if (strcmp(cmdType, "pong") == 0) {
    lastHeartbeatRecvMs = millis();
    Serial.println("[RX pong] heartbeat OK");
    return;
  }

  if (strcmp(cmdType, "servo_update") == 0) {
    JsonObject angles = doc["angles"];
    if (angles.isNull()) {
      Serial.println("[RX servo_update] WARN: empty angles");
      return;
    }
    String logIds = "";
    int updatedCount = 0;
    for (JsonPair kv : angles) {
      int servoId = atoi(kv.key().c_str());
      int angle = kv.value().as<int>();
      if (servoId >= 0 && servoId < 18) {
        targetServoAngles[servoId] = angle;
        updatedCount++;
        logIds += String(servoId) + "=" + String(angle) + " ";
      }
    }
    Serial.printf("[RX servo_update] %d servo(s): %s\n", updatedCount, logIds.c_str());

    bool faceDetected = doc["face_detected"] | false;
    bool dialogActive = doc["dialog_active"] | false;
    lastFaceDetected = faceDetected || dialogActive;
    videoFrameIntervalMs = lastFaceDetected ? (1000 / CAM_FPS_FACE) : (1000 / CAM_FPS_IDLE);
  }
  else if (strcmp(cmdType, "response") == 0) {
    const char* robotText = doc["robot_text"];
    const char* action = doc["action"];
    const char* emotion = doc["emotion"];

    if (robotText) {
      Serial.print("🦉 Soren: ");
      Serial.println(robotText);
    }
    if (emotion) {
      Serial.printf("   Emotion: %s\n", emotion);
    }
    if (action && strlen(action) > 0) {
      Serial.printf("🎬 Action: %s\n", action);
    }

    JsonArray servoAngles = doc["servo_angles"];
    if (!servoAngles.isNull()) {
      int i = 0;
      String logAngles = "";
      for (JsonVariant v : servoAngles) {
        if (i >= 18) break;
        int a = v.as<int>();
        targetServoAngles[i] = a;
        logAngles += String(a) + " ";
        i++;
      }
      Serial.printf("[RX response] servo_angles[%d]: %s\n", i, logAngles.c_str());
    }
  }
  else if (strcmp(cmdType, "audio_mode") == 0) {
    const char* mode = doc["output_mode"];
    if (mode) {
      audioMode = String(mode);
      Serial.printf("🔊 Audio mode changed to: %s\n", audioMode.c_str());
    }
  }
  else if (strcmp(cmdType, "backlight") == 0) {
    bool enabled = doc["enabled"] | false;
    setStandBacklight(enabled);
  }
  else if (strcmp(cmdType, "request_state") == 0) {
    // Сервер только что (пере)подключил нас и просит реальное состояние —
    // серв и подсветки — чтобы не работать по сбитым/дефолтным данным после
    // своего рестарта. Отвечаем тем, что физически выставлено ПРЯМО СЕЙЧАС.
    sendDeviceState();
  }
  else {
    Serial.printf("[WS] Unhandled type: %s\n", cmdType);
  }
}

void sendDeviceState() {
  StaticJsonDocument<640> doc;
  doc["type"] = "device_state";
  JsonObject angles = doc.createNestedObject("angles");
  for (int i = 0; i < 18; i++) {
    angles[String(i)] = currentServoAngles[i];
  }
  doc["backlight"] = standBacklightOn;
  String payload;
  serializeJson(doc, payload);
  webSocket.sendTXT(payload);
  Serial.println("[TX device_state] реальное состояние (сервы + подсветка) отправлено на сервер");
}

// ==================== ПОДСВЕТКА ====================
void standLedBootAnimation() {
  standLed.clear();
  standLed.setBrightness(255);
  standLed.show();

  for (int i = 0; i < STAND_LED_COUNT; i++) {
    standLed.setPixelColor(i, standLed.Color(WARM_WHITE_R, WARM_WHITE_G, WARM_WHITE_B));
    standLed.show();
    delay(1200 / STAND_LED_COUNT);
  }

  delay(400);

  for (int b = 255; b >= 0; b -= 15) {
    standLed.setBrightness(b);
    standLed.show();
    delay(20);
  }
  standLed.setBrightness(255);
  standLed.clear();
  standLed.show();
}

void setStandBacklight(bool on) {
  if (on == standBacklightOn) return;
  standBacklightOn = on;

  if (on) {
    for (int i = 0; i < STAND_LED_COUNT; i++) {
      standLed.setPixelColor(i, standLed.Color(WARM_WHITE_R, WARM_WHITE_G, WARM_WHITE_B));
    }
  } else {
    standLed.clear();
  }
  standLed.show();

  if (!on) {
    delay(2);
    standLed.clear();
    standLed.show();
  }

  Serial.printf("💡 Подсветка: %s\n", on ? "ВКЛ" : "выкл");
}

// ==================== СЕРВОПРИВОДЫ ====================
// Duty для прямого GPIO-серво (500-2500мкс импульс @ 50Гц = 20000мкс период),
// пересчитано под РЕАЛЬНОЕ разрешение SERVO_GPIO_LEDC_RES_BITS (14 бит на S3),
// а не захардкоженные под несуществующие 16 бит числа, как раньше.
int gpioServoDuty(int angle) {
  const long minDuty = 500L  * (SERVO_GPIO_LEDC_MAX_DUTY + 1) / 20000L;  // ~410
  const long maxDuty = 2500L * (SERVO_GPIO_LEDC_MAX_DUTY + 1) / 20000L;  // ~2048
  return map(angle, 0, 180, (int)minDuty, (int)maxDuty);
}
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

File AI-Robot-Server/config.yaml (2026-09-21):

# Конфигурация Сорена — Vector RAG + Qdrant + LoRA

# === Производительность ===
# fast_mode: true — максимальная скорость ответа. Отключает всё, что не
# обязательно для самого факта диалога и его тратит время/диск:
#   - Vector RAG (Qdrant + sentence-transformers энкодер, канон мира)
#   - Долгосрочная память (Qdrant: диалоги/факты/эмоциональные моменты)
#   - Сохранение/чтение JSON-профиля пользователя на диск
#   - Полный системный промпт (Soren.txt, ~9700 симв.) — вместо него
#     используется короткий (character/Soren_short.txt)
# Остаётся только короткая память последних реплик в RAM (нужна, чтобы Сорен
# не забывал, о чём речь в пределах текущего разговора) — она не пишется на
# диск и не измеряется в него, поэтому не влияет на скорость ответа.
performance:
    fast_mode: true

server:
    host: "0.0.0.0"
    port: 8765

# === Vector RAG (Qdrant + Sentence-Transformers) ===
qdrant:
    path: "./qdrant_storage" # Путь к локальной БД
    encoder_model: "sentence-transformers/paraphrase-multilingual-MiniLM-L12-v2"

# === Память ===
memory:
    short_term_max: 6 # Макс. реплик в RAM (короткая история для связности диалога)
    long_term_enabled: false # Qdrant LTM выключен — при fast_mode: true игнорируется в любом случае
    qdrant_host: "localhost"
    qdrant_port: 6333
    collections:
        emotional_moments: "soren_emotional_moments"
        dialogue_turns: "soren_dialogue_turns"
        facts: "soren_facts"
        rag_chunks: "soren_rag_chunks"

# === Fine-tuning / LoRA ===
lora:
    enabled: false
    # Дообученная (soren_lora_v1.gguf) модель оказалась дефектной — откатились на
    # базовую qwen2.5-7b-instruct. Если позже появится рабочий адаптер/слитая модель —
    # укажи путь ниже. path — это путь именно к ОТДЕЛЬНОМУ адаптеру (не к слитой модели,
    # иначе при enabled=true LoRA применится поверх уже вплавленной версии — задвоение).
    path: "models/soren_lora_v1.gguf"
    scale: 1.0
    rank: 16
    alpha: 32

# === STT ===
stt:
    mode: "local" # local / cloud
    whisper_model: "small"
    device: "cpu"
    compute_type: "int8"
    # Куратированный список размеров Whisper для выпадающего списка в /panel.
    # Выбор применяется сразу (faster-whisper перезагружается с новым размером).
    whisper_models:
        - id: "tiny"
          label: "Tiny — максимальная скорость"
        - id: "base"
          label: "Base"
        - id: "small"
          label: "Small — баланс скорости и точности"
        - id: "medium"
          label: "Medium — точнее, медленнее"

# === TTS ===
tts:
    mode: "cloud" # local / cloud / edge — облако (edge-tts): не грузит CPU ноутбука синтезом речи
    silero_speaker: "aidar"
    silero_pitch_semitones: 1.5
    silero_rate: 1.05
    edge_voice: "ru-RU-DmitryNeural"
    edge_speed: 1.0
    edge_pitch: "+15Hz"

# === LLM ===
llm:
    mode: "cloud" # local / cloud — облако (Hugging Face Inference Providers): секунды на ответ вместо минуты на слабом CPU
    local_model_path: "models/qwen2.5-7b-instruct-Q4_K_M.gguf" # старая рабочая база (дообученная была дефектной, откат)
    n_ctx: 2048 # при fast_mode: true промпт короткий (Soren_short.txt, без RAG) — большой контекст больше не нужен
    n_threads: 4
    temperature: 0.6
    repeat_penalty: 1.15
    # Hugging Face Inference Providers: "<model_id>:<провайдер|fastest|cheapest>".
    # Llama 3.3 70B Instruct — НЕ reasoning-модель (в отличие от gpt-oss), отвечает сразу,
    # без скрытой цепочки рассуждений. :fastest уводит на Cerebras/Groq (сотни-тысячи ток/сек).
    cloud_model: "meta-llama/Llama-3.3-70B-Instruct:fastest"
    cloud_api_key: "" # Берётся из .env HF_TOKEN (huggingface.co/settings/tokens, право "Make calls to Inference Providers")
    # Куратированные списки моделей для выпадающего списка в /panel (AI Core).
    # Выбор в панели применяется сразу — движок перезагружается с новой моделью
    # без рестарта сервера. "id" — то, что летит в POST /llm_model.
    local_models:
        - id: "qwen2.5-7b-q4"
          label: "Qwen2.5 7B Instruct (Q4_K_M)"
          path: "models/qwen2.5-7b-instruct-Q4_K_M.gguf"
        - id: "mistral-7b-instruct-q4"
          label: "Mistral 7B Instruct v0.3 (Q4_K_M)"
          path: "models/mistral-7b-instruct-v0.3.Q4_K_M.gguf"
    cloud_models:
        - id: "llama-3.3-70b-fastest"
          label: "Llama 3.3 70B Instruct (fastest)"
          model: "meta-llama/Llama-3.3-70B-Instruct:fastest"
        - id: "gpt-oss-120b-fastest"
          label: "GPT-OSS 120B (fastest)"
          model: "openai/gpt-oss-120b:fastest"
        - id: "qwen2.5-72b-fastest"
          label: "Qwen2.5 72B Instruct (fastest)"
          model: "Qwen/Qwen2.5-72B-Instruct:fastest"

# === Vision ===
vision:
    pose_tracking: true
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

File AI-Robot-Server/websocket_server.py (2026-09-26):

"""WebSocket сервер - связь с ESP32 и веб-интерфейсом + голосовое общение"""
import os
import asyncio
import json
import logging
import base64
import io
import wave
import tempfile
from pathlib import Path
from typing import Set, Optional, Dict, Tuple, List
from fastapi import FastAPI, WebSocket, WebSocketDisconnect, UploadFile, File, Form, Request
from fastapi.responses import HTMLResponse, JSONResponse, RedirectResponse
from fastapi.staticfiles import StaticFiles
from modules.robot_brain import RobotBrain
from modules.idle_thoughts import IdleThoughts
from modules.micro_motion import MicroJitter
from modules.gamepad_input import GamepadInput
from modules.wake_word import strip_wake_word
from modules.animation_loader import animation_book
from modules.auth import create_session_token, verify_session_token, is_valid_device_ping
from modules import backlight_state
from modules.backlight import is_night
from config.settings import (
    SERVER_HOST, SERVER_PORT,
    VIDEO_PANEL_MIN_INTERVAL_SEC, VIDEO_PANEL_JPEG_QUALITY,
    SERVO_UPDATE_MIN_INTERVAL_SEC,
    PANEL_PASSWORD, DEVICE_KEY,
    SESSION_COOKIE_NAME, SESSION_SHORT_MAX_AGE_SEC, SESSION_REMEMBER_MAX_AGE_SEC,
    BACKLIGHT_LATITUDE, BACKLIGHT_LONGITUDE, BACKLIGHT_TIMEZONE, BACKLIGHT_CHECK_INTERVAL_SEC,
)

logging.basicConfig(
    level=logging.INFO,
    format='%(asctime)s - %(name)s - %(levelname)s - %(message)s'
)
logger = logging.getLogger(__name__)

app = FastAPI(title="Robot AI Server - Soren", version="3.0")

# Статика для новой панели (изображение совы + фон) — файлы лежат рядом с этим
# скриптом в static/panel/. Если папки нет (например, при первом деплое) —
# создаём пустую, чтобы mount() не падал; картинки нужно положить туда вручную
# (owl-cutout.png, bg-nature.jpg — присланы вместе с этим файлом).
PANEL_ASSETS_DIR = Path(__file__).resolve().parent / "static" / "panel"
PANEL_ASSETS_DIR.mkdir(parents=True, exist_ok=True)
app.mount("/panel-assets", StaticFiles(directory=str(PANEL_ASSETS_DIR)), name="panel-assets")

robot_brain: RobotBrain = None
idle_thoughts: IdleThoughts = None
micro_jitter: MicroJitter = None
gamepad_input: GamepadInput = None
active_connections: Set[WebSocket] = set()

# Разделяем подключения /ws на "устройство" (ESP32, шлёт бинарные AUDI/VIDE кадры)
# и "панель" (браузер, инструментальная панель). Новое соединение по умолчанию
# считается панелью и переклассифицируется в устройство при первом бинарном пакете —
# так ESP32 не грузится ненужными ей JSON-кадрами видео.
panel_connections: Set[WebSocket] = set()
device_connections: Set[WebSocket] = set()

_last_panel_frame_ts = None

# Для каждого устройства помним, что и когда ему последний раз реально отправляли,
# чтобы слать: а) не чаще SERVO_UPDATE_MIN_INTERVAL_SEC, б) только ИЗМЕНИВШИЕСЯ углы
# (delta), а не все 18 на каждый кадр — интерполяция на ESP32 и так плавно доедет
# между редкими целями (см. interpolateServos в прошивке).
_last_servo_send: Dict[WebSocket, Tuple[float, Optional[List[int]]]] = {}

# Хочет ли конкретная панель получать видео (чекбокс "Показывать видео") —
# по умолчанию True для новых подключений, пока панель явно не скажет иначе.
panel_wants_video: Dict[WebSocket, bool] = {}

# ===== ОБРАТНАЯ СВЯЗЬ ОТ ПЛАТЫ (device_state) =====
# Когда соединение только что распознано как устройство (ESP32), ждём от него
# {"type":"device_state", ...} с реальными углами серв/состоянием подсветки —
# см. _handle_new_device_connection(). Событие в этом словаре "будится"
# обработчиком device_state (см. handle_text_message), либо срабатывает
# таймаут DEVICE_STATE_REPLY_TIMEOUT_SEC (совместимость со старой прошивкой,
# которая device_state ещё не шлёт).
_state_report_events: Dict[WebSocket, asyncio.Event] = {}
DEVICE_STATE_REPLY_TIMEOUT_SEC = 1.5

# ===== РАЗДЕЛЬНЫЕ РЕЖИМЫ АУДИО =====
audio_input_mode = "robot"   # "robot" = ESP32 микрофон, "local" = микрофон ноутбука
audio_output_mode = "robot"  # "robot" = ESP32 динамик, "local" = наушники ноутбука

# ===== LIFECYCLE =====

@app.on_event("startup")
async def startup():
    global robot_brain
    logger.info("🦉 Запуск сервера Сорена...")
    robot_brain = RobotBrain()
    robot_brain.on_servo_frame = broadcast_servo_state
    # Fallback: подключаем напрямую к ServoController, чтобы ручное управление
    # из панели (servo / servo_multi), анимации и плавный возврат в дефолт
    # уходили и на ESP32, и в панель (см. broadcast_servo_state)
    robot_brain.servos.on_servo_frame = broadcast_servo_state
    robot_brain.start_background_tasks()
    asyncio.create_task(_backlight_loop())

    global idle_thoughts
    idle_thoughts = IdleThoughts(
        play_animation=robot_brain.servos.play_animation,
        on_frame=broadcast_servo_state,
    )
    idle_thoughts.start()

    global micro_jitter
    micro_jitter = MicroJitter(
        get_current_angles=robot_brain.servos.get_current_angles,
        on_frame=broadcast_servo_state,
    )
    micro_jitter.start()

    global gamepad_input
    gamepad_input = GamepadInput(handle_command=dispatch_command_with_sfx)
    gamepad_input.start()  # тихо не активируется, если геймпад/pygame не найдены

    logger.info(f"✅ Сервер готов: ws://{SERVER_HOST}:{SERVER_PORT}")
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

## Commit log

2026-07-19 add trigger
    [body_body_body(1).stl, body_body_body(2).stl, body_body_front panel.stl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]
2026-08-31 esp32s3 server
2026-08-31 Add quick answers, backlight and wake word. Fixed stt, tts, vision and face tracking. Full update interface
    [audio_buffer.py, backlight.py, backlight_state.py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]
2026-08-31 full update
    [back panel.stl, base (1).stl, base (2).stl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]
2026-09-21 add animations, feedback, smooth return servo to default, auto-refresh the panel after a reboot or animation
    [animation_loader.py, audio_buffer.py, config.yaml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]
2026-09-26 added arbiter, idle thoughts, jitter, build audio cache, semantic quick match, smooth lead in, safety, sfx(sound effects), motion primitives, gamepad input, gamepad cooldown; improved quick answers
    [arbiter.py, gamepad_input.py, idle_thoughts.py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]

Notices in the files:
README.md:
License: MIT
